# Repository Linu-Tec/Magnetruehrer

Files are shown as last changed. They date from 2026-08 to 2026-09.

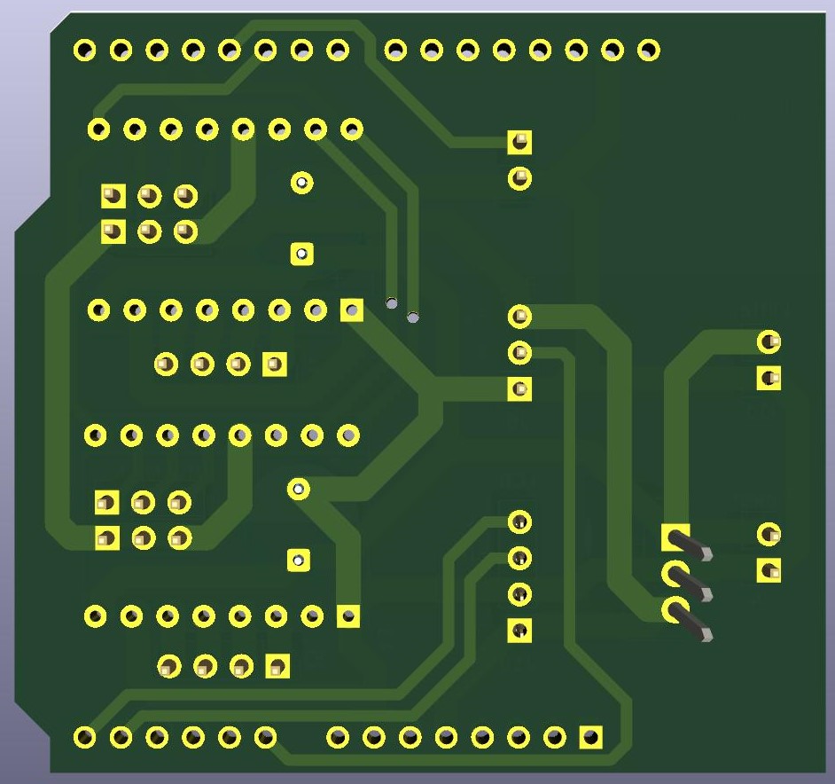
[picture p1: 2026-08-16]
Platine/Magnetrührer unten pcb.jpg

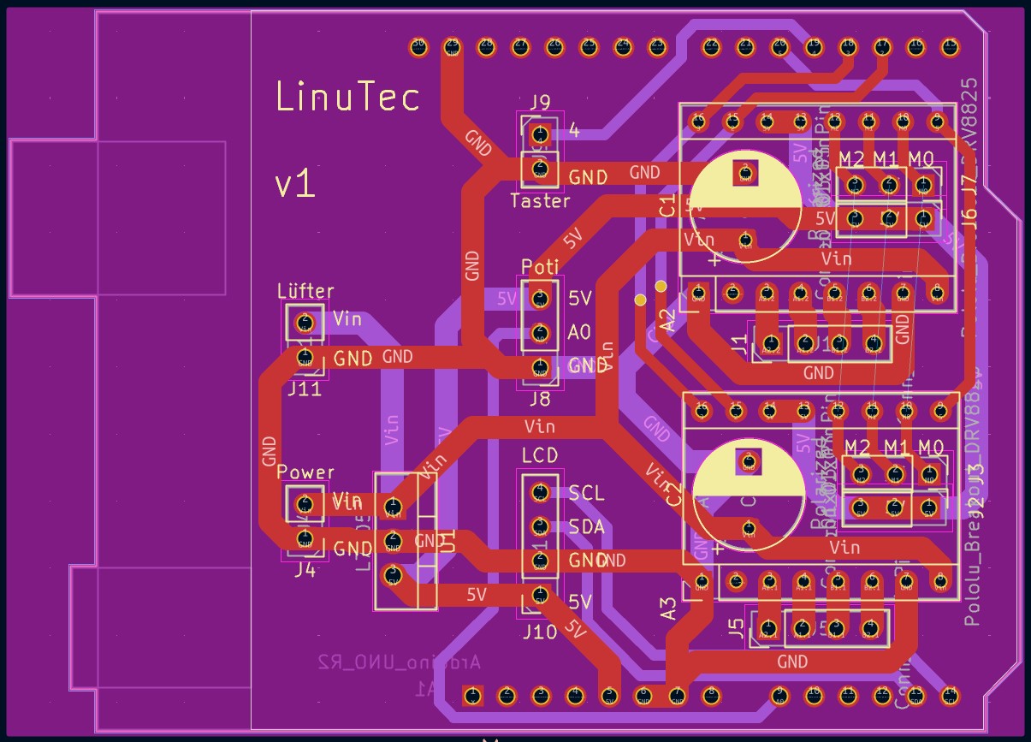
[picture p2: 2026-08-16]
Platine/Layout.jpg

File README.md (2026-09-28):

# Magnetrührer

## ✨ Features
* **Präzise Steuerung**: Jitterfreie Schrittmotor-Ansteuerung über Hardware-Timer 1.
* **Materialschonend**: Sanfter Anlauf und Abbremsen durch integrierte Beschleunigungsrampe.
* **Flackerfreies Display**: Ressourcenschonende, blockierungsfreie LCD-Aktualisierung im Hintergrund.

## 🚀 Bedienung
1. Gewünschte Drehzahl über das **Potentiometer** vorwählen.
2. Den **Taster** einmal kurz drücken, um den Rührvorgang zu starten. Die Drehzahl läuft automatisch rampenförmig an.
3. Erneutes Drücken des Tasters stoppt den Motor sofort.

## 🖼 Bild
Magnetrührer komplett

## 📂 Repository-Struktur

* `/firmware` - Enthält den Arduino-Quellcode (`.ino`).
* `/hardware` - Schaltpläne, Platinenlayouts (KiCad-Projektdateien) und Gerber-Dateien.
* `/3d-prints` - STL-, DXF- oder STEP-Dateien für das Gehäuse.
* `/assets` - Bilder und Grafiken für die Dokumentation.

## 🔌 Pin-Belegung (Arduino Uno)

| Peripherie | Arduino Pin | Funktion |
| :--- | :---: | :--- |
| **Schrittmotor (STEP)** | D2 | Impulsausgabe für Drehzahl |
| **Schrittmotor (DIR)** | D3 | Richtungssteuerung |
| **Taster (Button)** | D4 | Start / Stopp (interner Pull-up) |
| **Treiber (ENABLE)** | D5 | Aktivierung der Motortreiber |
| **Potentiometer** | A0 | Analoge Drehzahleinstellung |

# Material
## 📦 Stückliste (Bill of Materials)

Hier findest du alle elektronischen Komponenten, die für den Aufbau der Platine benötigt werden.

| Status | Bauteil (Designator) | Beschreibung | Menge | Gehäuse / Footprint |
| :---: | :--- | :--- | :---: | :--- |
| 🧠 | **Arduino UNO (A1)** | Steuerzentrale (Mikrocontroller-Board) | 1 | `Arduino_UNO_R2` |
| 🔌 | **DRV8825 (A2, A3)** | Schrittmotortreiber (Pololu-Breakout) | 1 | `Breakout-16_15.2x20.3mm` |
| 🔋 | **L7805 (U1)** | 5V Linear-Spannungsregler | 1 | `TO-220-3_Vertical` |
| ⚡ | **C_Polarized (C1, C2)**| Elektrolytkondensator (Stützkondensator) | 1 | `Radial_D8.0mm_P5.00mm` |
| 📟 | **LCD-Connector (J10)**| Buchsenleiste für das I2C-Display | 1 | `PinSocket_1x04_P2.54mm_V` |
| 🌀 | **Lüfter (J11)** | Stiftleiste für den Gehäuselüfter | 1 | `PinHeader_1x02_P2.54mm_V` |
| ⚙️ | **Microstepping (J2,J3,J6,J7)**| Jumper-Stiftleisten für Schrittauflösung | 4 | `PinHeader_1x03_P2.54mm_V` |
| 🏎️ | **Motor (J1, J5)** | Stiftleiste für Schrittmotor-Anschluss | 2 | `PinHeader_1x04_P2.54mm_V` |
| 🔌 | **Power In (J4)** | Stiftleiste für die Stromversorgung | 1 | `PinHeader_1x02_P2.54mm_V` |
| 🎛️ | **Poti (J8)** | Stiftleiste für Drehzahl-Potentiometer | 1 | `PinHeader_1x03_P2.54mm_V` |
| 🔘 | **Taster (J9)** | Stiftleiste für Start/Stopp-Taster | 1 | `PinHeader_1x02_P2.54mm_V` |

> 💡 **Tipp:** Wenn du die Platine professionell fertigen lassen möchtest (z. B. bei JLCPCB), kannst du die Spalte `LCSC Part #` in deiner EDA-Software (z. B. KiCad) pflegen, um die Bauteile beim Bestellen direkt automatisch bestücken zu lassen (PCBA).

### ⚙️ Microstepping-Konfiguration (Jumper J2, J3, J6, J7)

Der Schrittmotortreiber DRV8825 unterstützt verschiedene Schrittauflösungen. Für eine flüssige Rotation des Magneten wird standardmäßig das **1/32-Stepping** empfohlen.

| Auflösung | Jumper M0 (1) | Jumper M1 (2) | Jumper M2 (3) |
| :--- | :---: | :---: | :---: |
| Vollschritt (Full step) | LOW (off) | LOW (off) | LOW (off) |
| Halbschritt (Half step) | HIGH (on) | LOW (off) | LOW (off) |
| 1/4 Schritt | LOW (off) | HIGH (on) | LOW (off) |
| 1/8 Schritt | HIGH (on) | HIGH (on) | LOW (off) |
| 1/16 Schritt | LOW (off) | LOW (off) | HIGH (on) |
| **1/32 Schritt (Empfohlen)** | **HIGH (on)** | **HIGH (on)** | **HIGH (on)** |

## 🔩 Mechanische Komponenten & Zubehör

| Komponente | Beschreibung | Menge | Detail / Abmessung |
| :--- | :--- | :---: | :--- |
| **Schrittmotor** | NEMA 17 Schrittmotor | 1 | 1.8° Schrittwinkel |
| **Dauermagnete** | Neodym-Magnete (für den Rotor) | 2 | Block- oder Scheibenmagnete (z. B. N52) |
| **3D-Druckteile** | Gehäusebasis, Deckel und Magnet-Halterung | 1 | Eigene STL-Dateien (siehe `/3d-prints`) |
| **Rührfisch** | PTFE-beschichteter Magnet-Rührstab | 1 | Standardlänge (z. B. 25-30 mm) |
| **Schrauben** | Befestigung für Motor und Gehäuse | 1 Satz| M3 / M4 Innensechskant |

## 💻 Software-Installation

1. Installiere die [Arduino IDE](https://arduino.cc).
2. Installiere die benötigte Bibliothek über den Bibliotheksverwalter:
   * `LiquidCrystal_I2C` (von Frank de Brabander).
3. Öffne die Code-Datei im Ordner `/firmware`.
4. Verbinde den Arduino UNO per USB-Kabel mit dem PC.
5. Wähle das richtige Board (**Arduino Uno**) und den **COM-Port** aus.
6. Klicke auf **Hochladen** (Upload).

# Platine
PCB logo_PNG

## 🛠️ Platine bestellen (Anleitung für JLCPCB)

Die benötigten Hardware- und Designdateien für das PCB befinden sich vollständig im Ordner `platine`. Um die Platine kostengünstig und schnell beim Hersteller **JLCPCB** fertigen zu lassen, folge einfach dieser Schritt-für-Schritt-Anleitung:

### 1. Daten vorbereiten
* Navigiere hier im GitHub-Repository in den Ordner `Platine`.
* Lade den dort hinterlegten **Gerber-Ordner bzw. die fertige `.zip`-Datei** herunter (z. B. `Gerber_PCB.zip`). 
* *Wichtig:* Die ZIP-Datei auf deinem Computer nicht entpacken, sie muss als komprimiertes Archiv hochgeladen werden!

### 2. Upload bei JLCPCB
* Öffne die Website von [JLCPCB](https://jlcpcb.com/?from=BTBNLQNBK).
* Klicke direkt auf der Startseite auf den Button **"Add Gerber File"** oder **"Instant Quote"**.
* Wähle die zuvor heruntergeladene **ZIP-Datei** aus dem Ordner `platine` aus.
* Das System analysiert die Datei nun automatisch. Nach wenigen Sekunden erscheint eine visuelle Vorschau der Platinen-Vorderseite und -Rückseite.

### 3. Empfohlene Einstellungen
Die Standardwerte von JLCPCB sind für dieses DIY-Projekt bereits optimal vorausgewählt. Du solltest lediglich folgende Punkte kurz überprüfen:
* **Base Material:** FR-4 (Standard)
* **Layers:** (2 Layer)
* **PCB Qty (Menge):** 5 Stück (Das ist das günstigste Minimum)
* **PCB Color (Farbe):** Freie Wahl (Grün ist Standard, Schwarz, Blau oder Rot sehen oft moderner aus)
* **Surface Finish:** *HASL(with lead)* für einfaches Löten zum günstigsten Preis, oder *LeadFree HASL* für eine bleifreie Variante.

### 4. Bestellung abschließen
* Scrolle nach unten und klicke auf den Button **"Save to Cart"**, um die Platinen in den Warenkorb zu legen.
* Klicke im Warenkorb auf **"Secure Checkout"**.
* Melde dich an oder erstelle ein kurzes Kundenkonto.
* Gib deine Lieferadresse ein. 
  * *Tipp für den Versand:* **Global Standard Shipping** ist sehr günstig, kümmert sich automatisch um die Zollabwicklung (IOSS) und dauert ca. 1–2 Wochen. Wer es eilig hat, wählt *DHL Express*.
* Bezahle die Bestellung sicher via PayPal oder Kreditkarte. Nach der Produktion (meist 2–3 Tage) wird das Paket direkt zu dir nach Hause geschickt.

## Ansicht von der Platine

Oben (Top)
Magnetrührer oben pcb

Unten (Bottom)
Magnetrührer unten pcb

# Schaltplan
Schaltplan groß

# Code

```
#include <Wire.h>
#include <LiquidCrystal_I2C.h>

// --- PIN DEFINITIONEN ---
const int PIN_STEP   = 2; 
const int PIN_DIR    = 3; 
const int PIN_BUTTON = 4; 
const int PIN_ENABLE = 5; 
const int PIN_POTI   = A0; 

// --- DISPLAY KONFIGURATION ---
LiquidCrystal_I2C lcd(0x27, 16, 2); 

// --- MOTOR CONFIGURATON ---
const int SCHRITTE_PRO_UMDREHUNG = 200; 

// --- VARIABLEN ---
volatile bool motorAktiv = false; 
bool letzterTasterStatus = HIGH;
unsigned long letzterDebounceZeitpunkt = 0;
const unsigned long debounceVerzoegerung = 50; 

int letzterPotiWert = -99;
const int POTI_SCHWELLENWERT = 3; 
long zielRpm = 0;
long aktuelleRpm = 0; 

// Variablen für die Beschleunigungsrampe
unsigned long letzteRampeZeit = 0;
const unsigned long rampeIntervall = 4; 

// Variablen für das Display-Update
unsigned long letzteDisplayAktion = 0;
const unsigned long displayIntervall = 30; 
int displaySchritt = 0;
long rpmFuerDisplay = 0;

// Variablen für den Hardware-Timer
volatile unsigned int timerZaehler = 60000;

void setup() {
  pinMode(PIN_STEP, OUTPUT);
  pinMode(PIN_DIR, OUTPUT);
  pinMode(PIN_ENABLE, OUTPUT);
  pinMode(PIN_BUTTON, INPUT_PULLUP);
  
  digitalWrite(PIN_ENABLE, HIGH); 
  digitalWrite(PIN_DIR, HIGH);
  
  // --- HARDWARE-TIMER1 INITIALISIEREN ---
  cli(); 
  TCCR1A = 0;
  TCCR1B = 0;
  TCNT1  = 0;
  OCR1A = 2000;            
  TCCR1B |= (1 << WGM12);  
  TCCR1B |= (1 << CS11);   
  TIMSK1 |= (1 << OCIE1A); 
  sei(); 

  lcd.init();
  lcd.backlight();
  
  lcd.setCursor(0, 0);
  lcd.print("Magnetruehrer");
  lcd.setCursor(0, 1);
  lcd.print("Bereit...");
  delay(1500);
  lcd.clear();
  
  // Neues Layout mit mehr Platz für die Einheit
  lcd.setCursor(0, 0);
  lcd.print("Status: AUS");
  lcd.setCursor(0, 1);
  lcd.print("Rpm:       0 U/min"); // Start-Layout vordefiniert
}

// --- INTERRUPT SERVICE ROUTINE ---
ISR(TIMER1_COMPA_vect) {
  if (motorAktiv && aktuelleRpm > 0) {
    PORTD |= (1 << PD2);  
    delayMicroseconds(2);
    PORTD &= ~(1 << PD2); 
    
    OCR1A = timerZaehler; 
  }
}

void loop() {
  // 1. TASTER AUSLESEN & ENTPRELLEN
  int tasterLesen = digitalRead(PIN_BUTTON);
  if (tasterLesen != letzterTasterStatus) {
    letzterDebounceZeitpunkt = millis();
  }

  if ((millis() - letzterDebounceZeitpunkt) > debounceVerzoegerung) {
    if (tasterLesen == LOW && !motorAktiv) {
      motorAktiv = true;
      digitalWrite(PIN_ENABLE, LOW); 
      letzterPotiWert = -99; 
      aktuelleRpm = 10; 
    } else if (tasterLesen == LOW && motorAktiv) {
      motorAktiv = false;
      digitalWrite(PIN_ENABLE, HIGH); 
      aktuelleRpm = 0;
    }
  }
  letzterTasterStatus = tasterLesen;

  // 2. POTI AUSLESEN
  int potiWert = analogRead(PIN_POTI);
  
  if (abs(potiWert - letzterPotiWert) > POTI_SCHWELLENWERT) {
    letzterPotiWert = potiWert;
    zielRpm = map(potiWert, 0, 1023, 10, 850);
  }

  // 3. BESCHLEUNIGUNGSRAMPE
  if (motorAktiv && (millis() - letzteRampeZeit > rampeIntervall)) {
    letzteRampeZeit = millis();
    
    if (aktuelleRpm < zielRpm) {
      aktuelleRpm++; 
    } else if (aktuelleRpm > zielRpm) {
      aktuelleRpm--; 
    }
    
    if (aktuelleRpm > 0) {
      timerZaehler = 600000 / aktuelleRpm;
      if (timerZaehler < 550) timerZaehler = 550; 
    }
  }

  // 4. DISPLAY HÄPPCHENWEISE AKTUALISIEREN
  if (millis() - letzteDisplayAktion > displayIntervall) {
    letzteDisplayAktion = millis();
    rpmFuerDisplay = motorAktiv ? zielRpm : 0; 

    switch (displaySchritt) {
      case 0:
        lcd.setCursor(8, 0);
        if (motorAktiv) lcd.print("AN ");
        else            lcd.print("AUS");
        displaySchritt++;
        break;
      case 1:
        // Die Zahl startet jetzt zwei Stellen weiter links (Stelle 6 statt 8)
        lcd.setCursor(6, 1);
        displaySchritt++;
        break;
      case 2:
        if (rpmFuerDisplay < 1000) lcd.print(" ");
        else lcd.print(rpmFuerDisplay / 1000);
        displaySchritt++;
        break;
      case 3:
        if (rpmFuerDisplay < 100) lcd.print(" ");
        else lcd.print((rpmFuerDisplay % 1000) / 100);
        displaySchritt++;
        break;
      case 4:
        if (rpmFuerDisplay < 10) lcd.print("0");
        else lcd.print((rpmFuerDisplay % 100) / 10);
        displaySchritt++;
        break;
      case 5:
        lcd.print(rpmFuerDisplay % 10);
        displaySchritt++;
        break;
      case 6:
        // Schreibt die Einheit mit ausreichend Platz dahinter
        lcd.print(" U/min  "); 
        displaySchritt = 0; 
        break;
    }
  }
}
```

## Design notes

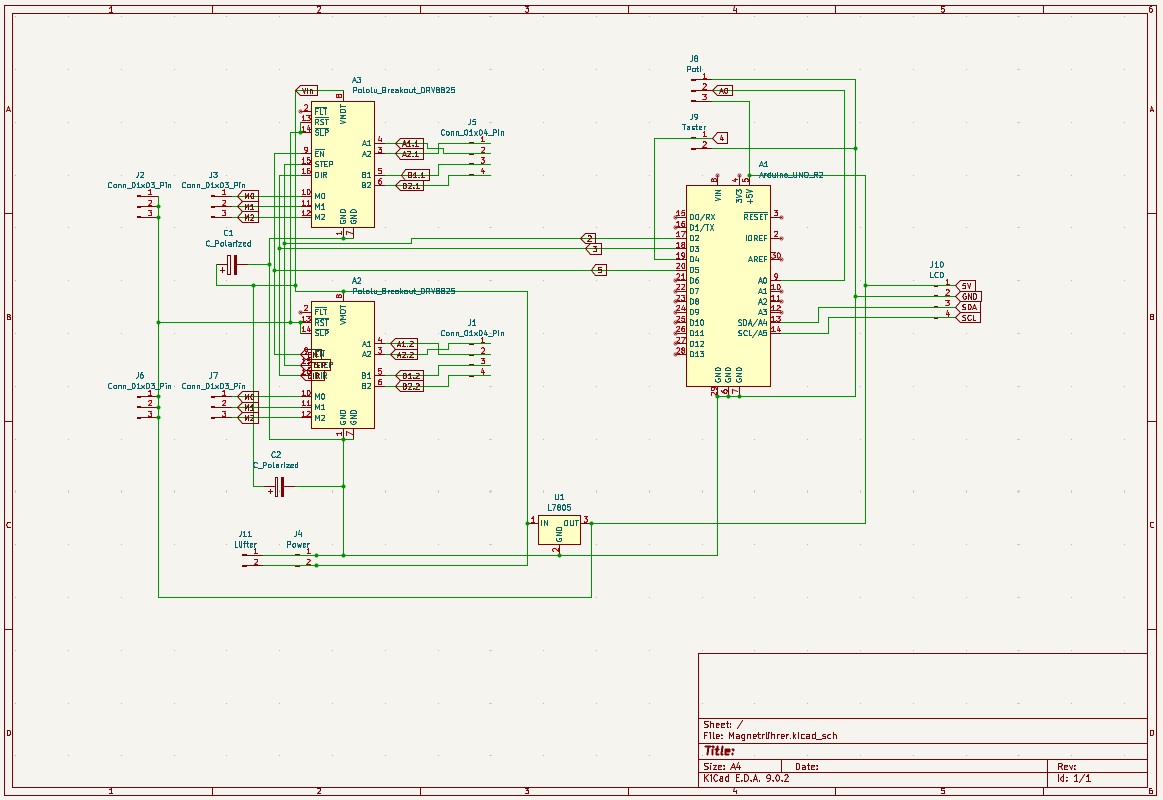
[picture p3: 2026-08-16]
Platine/Schaltplan.jpg

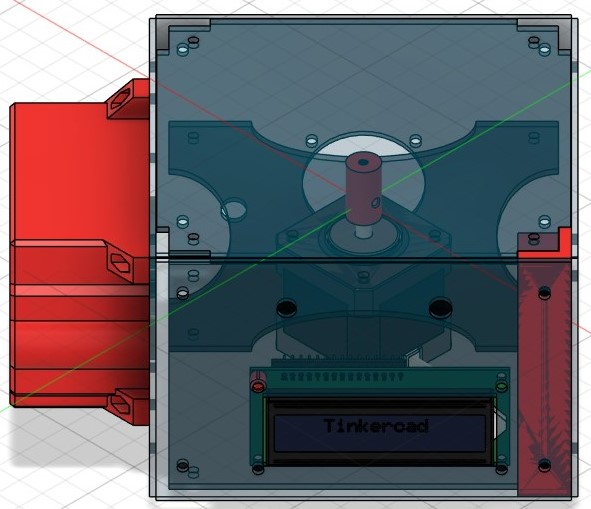
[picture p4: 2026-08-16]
Gehäuse/Magnetrührer komplett.jpg

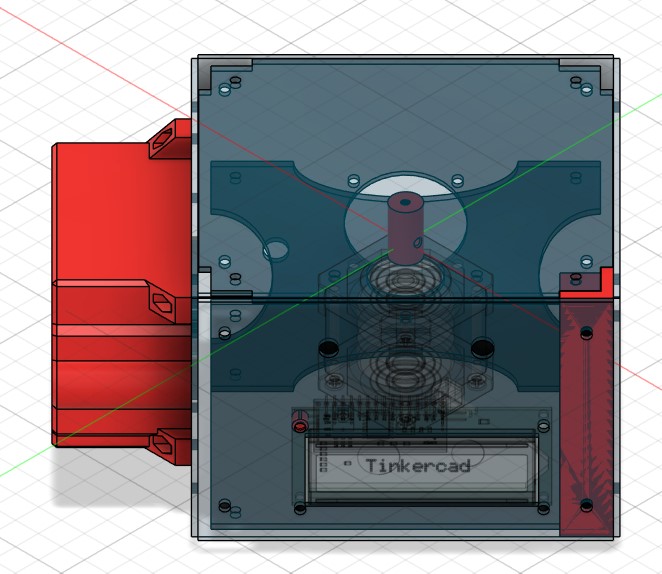
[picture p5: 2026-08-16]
Gehäuse/Magnetrührer.jpg

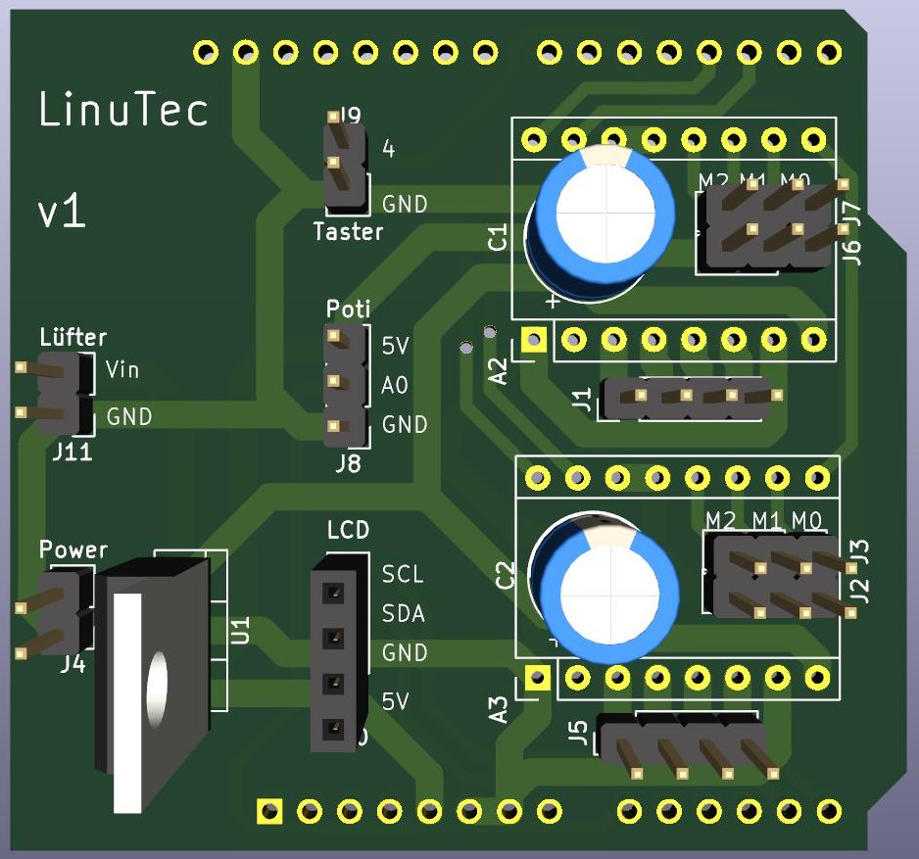
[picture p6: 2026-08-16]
Platine/Magnetrührer oben pcb.jpg

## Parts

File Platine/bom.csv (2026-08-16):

Designator | Footprint | Quantity | Value | LCSC Part #
A1 | Arduino_UNO_R2 | 1 | Arduino_UNO_R2
A2, A3 | Pololu_Breakout-16_15.2x20.3mm | 2 | Pololu_Breakout_DRV8825
C1, C2 | CP_Radial_D8.0mm_P5.00mm | 2 | C_Polarized
J1, J5 | PinHeader_1x04_P2.54mm_Vertical | 2 | Conn_01x04_Pin
J10 | PinSocket_1x04_P2.54mm_Vertical | 1 | LCD
J11 | PinHeader_1x02_P2.54mm_Vertical | 1 | Lüfter
J2, J3, J6, J7 | PinHeader_1x03_P2.54mm_Vertical | 4 | Conn_01x03_Pin
J4 | PinHeader_1x02_P2.54mm_Vertical | 1 | Power
J8 | PinHeader_1x03_P2.54mm_Vertical | 1 | Poti
J9 | PinHeader_1x02_P2.54mm_Vertical | 1 | Taster
U1 | TO-220-3_Vertical | 1 | L7805

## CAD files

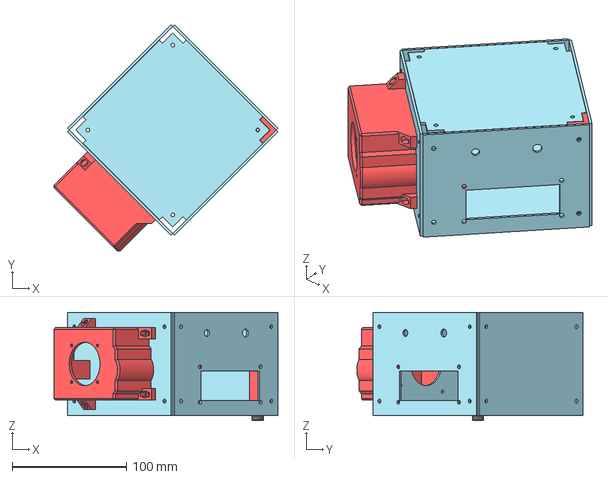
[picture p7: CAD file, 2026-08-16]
Gehäuse/Magnetrührer Gehäuse komplett.step
195.7 x 197.8 x 94.5 mm

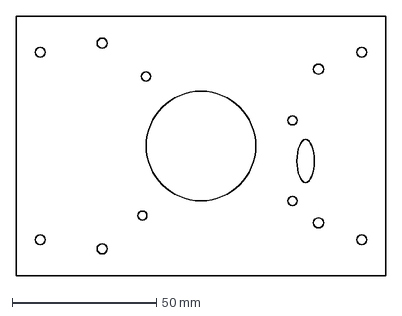
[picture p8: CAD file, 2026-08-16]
Gehäuse/Magnetrührer v3 Links Rechts Laser.dxf
128.0 x 90.0 mm

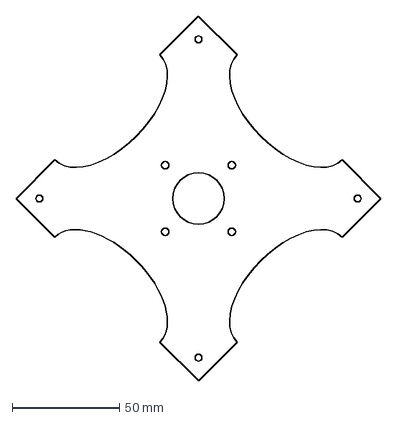
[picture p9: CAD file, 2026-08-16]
Gehäuse/Magnetrührer v3 Nema Mitte Laser.dxf
169.7 x 169.7 mm

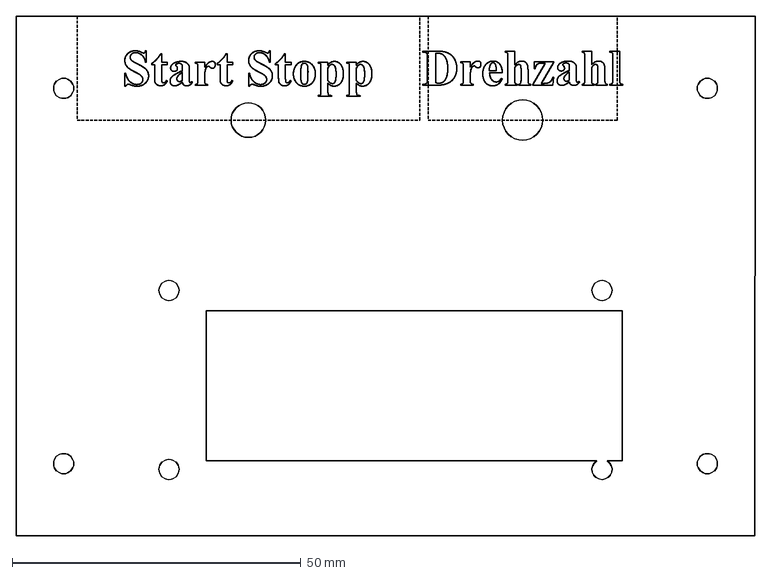
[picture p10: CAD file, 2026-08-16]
Gehäuse/Magnetrührer v3 Vorne Laser.dxf
128.0 x 90.0 mm

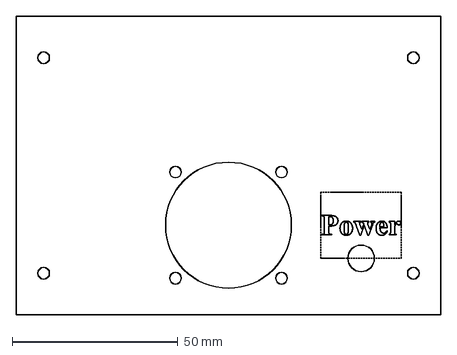
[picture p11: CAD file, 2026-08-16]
Gehäuse/Magnetrührer v3 Hinten Laser.dxf
128.0 x 90.0 mm

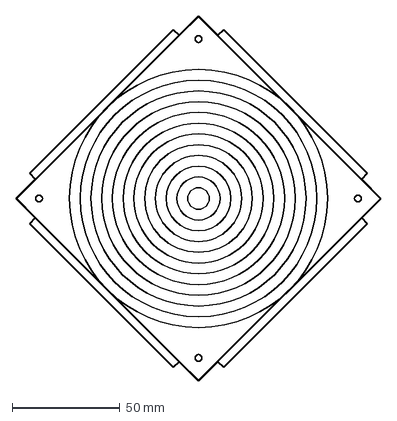
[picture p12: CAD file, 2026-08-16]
Gehäuse/Magnetrührer v3 Oben Unten Laser.dxf
169.7 x 169.7 mm

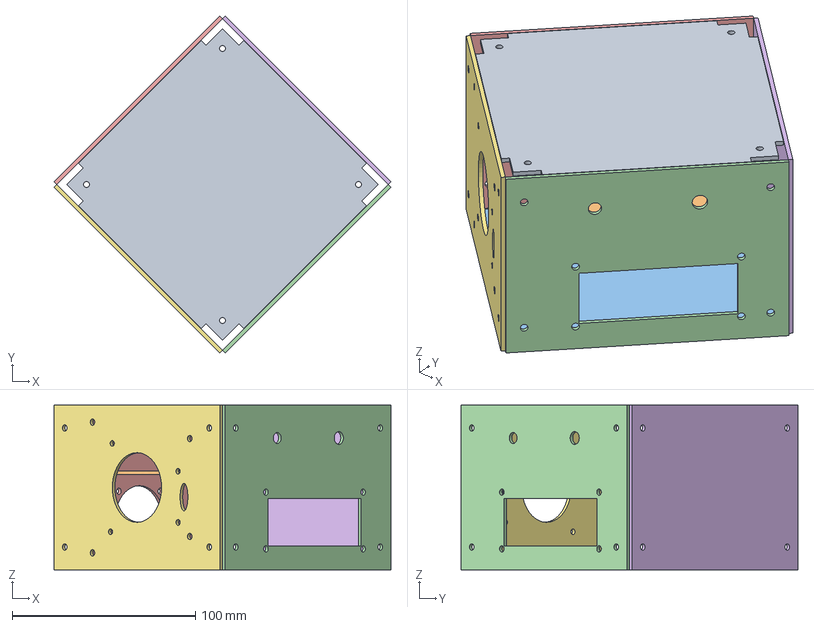
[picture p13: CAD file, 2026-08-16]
Gehäuse/Magnetrührer Arcylglas.step
183.8 x 183.8 x 90.0 mm

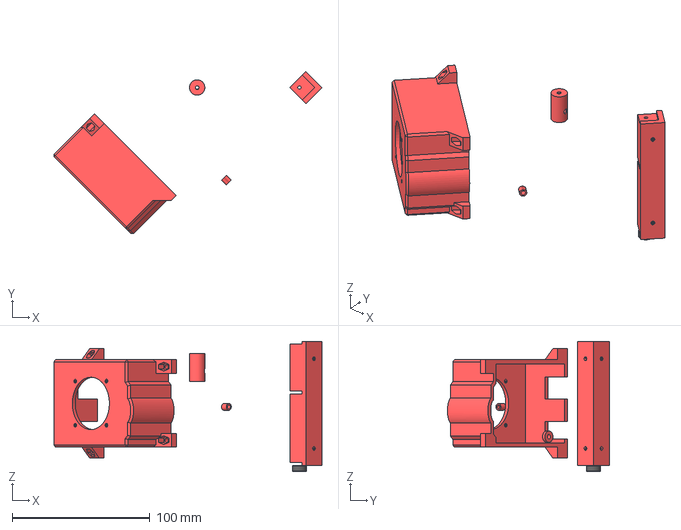
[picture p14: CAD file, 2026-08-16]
Gehäuse/Magnetrührer 3D Druck.step
194.3 x 117.6 x 94.5 mm

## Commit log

2026-08-16 Add Magnetruehrer Arduino sketch for motor control
2026-08-24 Enhance README with features and usage details
    Added features, operation instructions, image, and pinout table for Arduino Uno.
2026-08-24 Add .gitignore for Arduino and KiCad projects
2026-08-24 Enhance README with Bill of Materials section
    Added a detailed bill of materials (BOM) section with descriptions and quantities for electronic components required for the PCB assembly.
2026-09-24 Add JLCPCB ordering instructions to README
    Added detailed instructions for ordering PCBs from JLCPCB, including preparation, upload, recommended settings, and checkout process.
2026-09-24 Update README with corrected PCB layer information
